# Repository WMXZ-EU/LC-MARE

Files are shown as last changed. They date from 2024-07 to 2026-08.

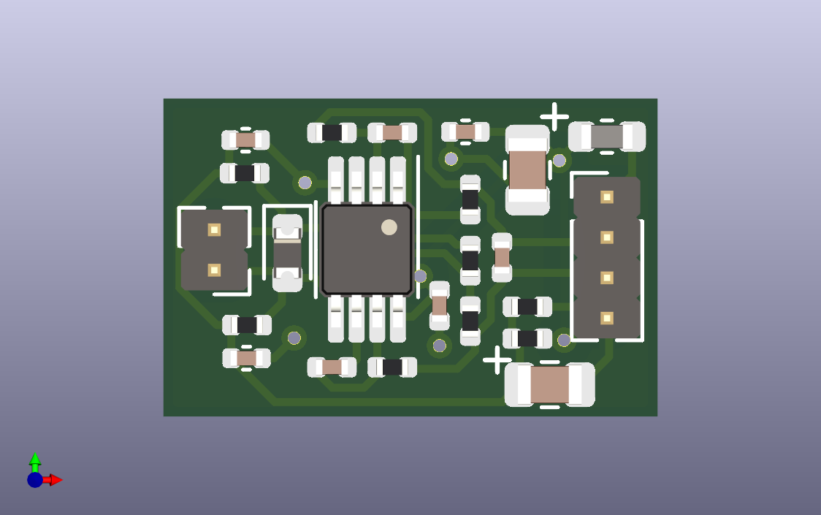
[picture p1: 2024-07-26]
KICAD/PreampV5-mare/PreampV5-mare.png

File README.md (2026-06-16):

# LC-MARE
Low-Cost Marine Acoustic REcorder. See detailed info in different folders
 
Actual preferred firmware verson is adalogger_V3

## Content
### 3D-models
contains some stl files for 3D printing
### adalogger_V2
first LC-Mare firmware uses only adalogger RP2040. Suitable for single hydrophone and sampling frequency up to 96 kHz
### adalogger_V3
improved LC-Mare firmware 
- for adalogger RP2040 (single hydrophone up to 96 kHz sampling frequency)
- for rp2350 based adafruit feather (stereo and up to 384 kHz sampling frequency)
### microPAM_V4
development version for three MCU types (RP2040, RP2350, Teensy4.1)
Work in Progress
### Documents
different files describing project and hardware construction
### KICAD
hardware desigh files for
- ADC (ADC_V2)
- preamp (PreampV5-mare)
- Base board (LC_PAMV4b)
- Libraries (for KICAD)
### Python
contains python based setup and analysis scripts

Of importance is a GUI (LC_Mare.py) that provides access to basic operations, like inspecting LC_mare file parameters, visualizing time series and spectra, to configure the firmware, to convert compressed to wav files, and to upload latest firmware

An compiled version (.exe) with supporting libraries may be found in

https://github.com/WMXZ-EU/LC-MARE/releases/download/LC_Mare_v1.0.0/LC_Mare.zip

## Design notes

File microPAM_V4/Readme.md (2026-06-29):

# microPAM V4

Firmware for a low-power **Passive Acoustic Monitor (PAM)** targeting three microcontroller boards. Records multi-channel audio via TDM (Time Division Multiplexed I2S) to SD card, with optional lossless integer compression, FFT-based directional sound intensity estimation, and online VAE-based acoustic classification.

Version: 4.3.0 — Copyright © 2026 Walter Zimmer. Released under the MIT License.

---

## Supported hardware

| Board | MCU | Channels | Max sample rate | DSP / Classifier |
|---|-----|---|---|---|
| Teensy 4.1 | i.MX RT1062 | 4 | 192 kHz | Yes (PROC_MODE 2 / 3 / 4) |
| Adafruit Feather RP2040 Adalogger | RP2040 | 1 | 192 kHz | No |
| Adafruit Feather RP2350 HSTX | RP2350 | 4 | 192 kHz | No |

All boards use a **TLV320ADC6140** analog front end (I2C configuration, programmable gain). The RP2350 board stores its deep DMA queue in 8 MB of on-board PSRAM.

ADC channel-count limits (hardware):

| `NCHAN_I2S` | Max `FSAMP` |
|---|---|
| 1 | 192 kHz |
| 2 | 384 kHz |
| > 2 | 192 kHz |

---

## Processing modes

Set `PROC_MODE` in [`config.h`](config.h):

| Value | Mode | Output file | Targets |
|---|---|---|---|
| 0 | Raw WAV | `.wav` | All |
| 1 | Integer compression (differential + bit-pack) | `.bin` | All |
| 2 | Compressed per-bin FFT magnitude spectrum | `.spc` | Teensy 4.1 only |
| 3 | Directional sound intensity (tetrahedral array) + compressed intensity vectors | `.int` | Teensy 4.1 only |
| 4 | DSP pipeline + 4-VAE classifier — latent means pushed to queue | `.vae` | Teensy 4.1 only |

PROC_MODE 2, 3, and 4 are silently downgraded to 1 on RP2040/RP2350 targets.

DSP modes (2 / 3 / 4) use asynchronous dispatch: `process()` snapshots the acquisition buffer and pends `IRQ_QTIMER3` (`DSP_IRQ_PRIORITY = 7×16`, below DMA) so the DMA ISR returns immediately. The DSP ISR performs the heavy computation and pushes results to the queue.

---

## Configuration

Edit [`config.h`](config.h) before building:

```c
#define T_ACQ   60    // recording window length (seconds)
#define T_ON     1    // on-time per duty cycle (minutes)
#define T_REP    0    // repeat interval; set < T_ACQ for continuous recording

#define FSAMP  192000 // sample rate (Hz)
#define PROC_MODE  4  // 0=raw WAV, 1=compressed, 2=spectrum, 3=intensity, 4=intensity+VAE (2/3/4: T4.1 only)

// #define USE_SYNTH_SIGNAL  // inject synthetic chirp every 100 calls (testing only)

// WAV file metadata
#define SRC_str "LC17"      // source/instrument ID
#define CMS_str "WMXZ"      // organisation
#define ART_str "WMXZ"      // creator
#define PRD_str "microPAM"  // product / activity
#define SBJ_str "______"    // area
#define NAM_str "Test"      // location ID
```

Key DSP/gain constants in [`src/global.h`](src/global.h):

```c
#define SHIFT  12    // bit-shift for integer compression
#define AGAIN  20    // ADC analogue gain (dB)
#define DGAIN   0    // ADC digital gain
```

Output scaling (in `src/process.cxx`):

| Mode | Scale factor | Formula |
|---|---|---|
| 2 (spectrum) | `scale2` | `1 << (31 − SHIFT)` |
| 3 / 4 (intensity) | `scale3` | `1 << (32 − SHIFT)` |

Detection parameters (PROC_MODE 3/4, Teensy 4.1):

```c
#define DETECT_ALPHA  0.01f  // background averaging rate (0.001 slow … 0.1 fast)
#define DETECT_THR    3.0f   // SNR threshold (Dblock / Dmean)
```

---

## DSP pipeline (Teensy 4.1, PROC_MODE 2 / 3 / 4)

```
process()            — snapshots acq_buffer → dsp_buffer, pends IRQ_QTIMER3 (async DSP ISR)
    │
    └─► dsp_isr()    — fires below DMA priority; does the heavy work per mode:
            │
            ├─ PROC_MODE 2 ─► spectrum_power()
            │                  spectrum_apply() — 50 %-overlap RFFT per channel → Z[]
            │                  per-bin magnitude sqrt(re²+im²) → scale2 → compress → queue (.spc)
            │
            └─ PROC_MODE 3/4 ─► dsp_apply()
                                 spectrum_apply()    — RFFT per channel → Z[]
                                 intensity_apply()   — cross-correlation → I[3×NSAMP], D[NSAMP]
                                 detection_apply()   — SNR, exponential background tracking
                                 classifier_trigger()— snapshot D[], pend IRQ_QTIMER4 (priority 128)
                                     │
                                     (ISR fires asynchronously)
                                 classifier_isr()    — 4 parallel VAE fwd+bwd+SGD on D_buf[] quarters
                                                     — exposes vae_mu[VAE_LAT_TOTAL], classifier_exec_us
                                 PROC_MODE 3: I[] → scale3 → compress → queue (.int)
                                 PROC_MODE 4: classifier ISR owns queue push of vae_mu → (.vae)
```

### VAE classifier (Teensy 4.1 only)

Four parallel online Variational Autoencoders, each trained incrementally on one quarter of the intensity spectrum `D[]`.

| Parameter | Value |
|---|---|
| Number of VAEs | 4 |
| Input per VAE (`VAE_QSAMP`) | `VAE_NSAMP / 4` (= 128 at 192 kHz, 4 ch) |
| Architecture per VAE | `QSAMP – 32 – 4 – 32 – QSAMP` |
| Latent dims per VAE (`VAE_LAT`) | 4 |
| Total exported latent means (`VAE_LAT_TOTAL`) | 16 |
| Learning rate | 1 × 10⁻⁴ (SGD) |
| KL weight β | 1 × 10⁻³ |
| Large weight storage | DMAMEM (RAM2) — W1[4][H][Q] and W4[4][Q][H] |
| IRQ | `IRQ_QTIMER4`, priority 128 |
| Model file | `/VAE_model.dat` on SD card root (loaded on boot, saved hourly and before hibernate) |
| Model backups | `/VAE_backup/VAE_model_YYYYMMDD_HHMM.dat` — timestamped snapshots |

All 16 latent means are available via `vae_mu[VAE_LAT_TOTAL]` (layout: `[vae0_μ0, …, vae0_μ3, vae1_μ0, …]`) and printed by the serial monitor each second. In PROC_MODE 4 they are also written to the `.vae` file via the queue.

---

## Architecture

```
Acquisition (DMA IRQ / core 1)
    └─► process()
            │  PROC_MODE 0: passthrough → queue
            │  PROC_MODE 1: differential encode + bit-pack → queue
            │  PROC_MODE 2/3/4: snapshot → pend IRQ_QTIMER3 (returns immediately)
            │
            └─► dsp_isr() [IRQ_QTIMER3, async]
                    │  PROC_MODE 2: spectrum magnitude → compress → queue
                    │  PROC_MODE 3: intensity → compress → queue
                    │  PROC_MODE 4: intensity → pend classifier ISR → queue (vae_mu)
                    └──────────────────────────────────────────────► queue

loop() / core 0
    └─► queue.pull() ──► logger() ──► SD card
```

- **RP2040 / RP2350**: acquisition on core 1 (`core1_main`); filing, RTC, and serial menu on core 0.
- **Teensy 4.1**: single-core; DMA ISR drives `process()` directly.
- The RP2350 queue (`MAX_QUEUE = 225`) is placed in PSRAM via a linker section attribute.

---

## Building

Requires [arduino-cli](https://arduino.github.io/arduino-cli/) installed at:

```
%LOCALAPPDATA%\Programs\Arduino IDE\resources\app\lib\backend\resources\arduino-cli.exe
```

Config directory: `%LOCALAPPDATA%\Arduino15`

```powershell
.\scripts\build.ps1            # all three targets
.\scripts\build.ps1 teensy     # Teensy 4.1 only
.\scripts\build.ps1 rp2040     # RP2040 Adalogger only
.\scripts\build.ps1 rp2350     # RP2350 HSTX only
```

Output goes to `build\<target>\`:

| Target | Binary | Format |
|---|---|---|
| Teensy 4.1 | `build\teensy\microPAM_V4.ino.hex` | Intel HEX (uploaded via Teensy Loader) |
| RP2040 | `build\rp2040\microPAM_V4.ino.uf2` | UF2 (drag-and-drop or arduino-cli) |
| RP2350 | `build\rp2350\microPAM_V4.ino.uf2` | UF2 (drag-and-drop or arduino-cli) |

> **RP2350 note:** always pass `psram=8mb` (the build script does this automatically). Without it the linker fails because the default `psram_length` is 0.

---

## Flashing (compile + upload)

```powershell
.\scripts\flash_teensy.ps1     # Teensy 4.1 — board must be connected
.\scripts\flash_rp2040.ps1     # RP2040 — normal connection or BOOTSEL+plug
.\scripts\flash_rp2350.ps1     # RP2350 HSTX — normal connection or BOOTSEL+plug
```

RP scripts try two paths in order:
1. BOOTSEL mass-storage drive (`RPI-RP2` / `RP2350`) — copies the `.uf2` directly.
2. Serial port — arduino-cli resets the board into the bootloader.

## Uploading pre-built firmware (upload only)

If you have received pre-built binaries (or already compiled with `build.ps1`) and only need to flash them without recompiling, use the upload-only scripts:

```powershell
.\scripts\upload_teensy.ps1    # Teensy 4.1
.\scripts\upload_rp2040.ps1    # RP2040 Adalogger
.\scripts\upload_rp2350.ps1    # RP2350 HSTX
```

These scripts read the binary directly from `build\<target>\` and abort with a clear message if no pre-built file is found there. The same two-path upload logic applies to the RP boards (BOOTSEL drive first, then serial port).

**Steps to flash a pre-built binary:**

1. Copy the `build\` folder (or the relevant sub-folder) from the source that provided the firmware onto your machine, keeping the path structure intact.
2. Connect the board:
   - **Teensy 4.1**: connect via USB; press the PROGRAM MODE button if prompted during upload.
   - **RP2040 / RP2350**: connect normally, or hold the **BOOTSEL** button while plugging in to force mass-storage mode.
3. Open a PowerShell terminal in the `microPAM_V4` directory and run the appropriate script:
   ```powershell
   .\scripts\upload_teensy.ps1   # or upload_rp2040.ps1 / upload_rp2350.ps1
   ```
4. Wait for `Upload OK`.

---

## Python tools

Three companion tools are provided in the `Python/` folder.  All require Python 3.10+ and the packages listed in `Python/requirements.txt`.

A ready-to-use virtual environment is included at `Python/.venv` (Python 3.14).  Install dependencies once with:

```powershell
Python\.venv\Scripts\pip.exe install -r Python\requirements.txt
```

To run from PyCharm, set the interpreter to `Python\.venv\Scripts\python.exe`.

See [`Docs/micropam_python_tools.md`](Docs/micropam_python_tools.md) for a full user guide.

### micropam_control — device configuration GUI

Configures and controls the PAM over USB serial without a terminal.

```powershell
Python\.venv\Scripts\python.exe Python\micropam_control.py
```

| GUI element | Serial command | Description |
|---|---|---|
| Port / Connect | — | Lists available COM ports; connects at 115200 baud (USB CDC, baud ignored) |
| UID display | `?u` | Board unique ID, fetched automatically on connect |
| t_acq / t_on / t_rep | `?a` / `!a` … | Recording timing parameters |
| fsamp | `?f` / `!f` | Sampling frequency |
| again | `?g` / `!g` | ADC analogue gain (dB) |
| Artist / Product / Name | `?n` / `!n` … | WAV metadata strings |
| Start Time | `?x` / `!x` | Scheduled start time string |
| h_rec 1–4 | `?1`…`?4` / `!1`…`!4` | Recording hour windows |
| Datetime / getRTC | `?d` | Read current RTC time from MCU into the field |
| Datetime / Set RTC | `!d` | Send the Datetime field value to the MCU RTC |
| Datetime / syncRTC | `!d` | Stamp PC time → field → MCU RTC in one click |
| Read all | all `?` keys | Queries every parameter and populates the GUI |
| Start / Stop | `s` / `e` | Start or stop acquisition |
| Print params | `p` | Print all parameters to the serial monitor |
| Reboot | `b` | Reboot the MCU |
| Hibernate hours / minutes | `x<n>` / `y<n>` | Enter low-power sleep |
| Raw send box | passthrough | Send any command directly |
| Serial monitor | — | Full-width scrolling output, auto-parses `key = value` responses |

### micropam_browser — data file browser and viewer

Browse, inspect, and visualise recorded data files without any additional software.

```powershell
Python\.venv\Scripts\python.exe Python\micropam_browser.py [folder]
```

Features:

- Sortable file list with mode, sample rate, channel count, and file size
- Right-click (or double-click) any file → **Show header info** — full WAV/IKEY parameter popup
- Right-click → **View data** (or press `v`) — mode-specific matplotlib plot:
  - **Mode 0/1**: time series per channel + spectrogram of channel 0
  - **Mode 2**: per-channel compressed spectrum waterfall
  - **Mode 3**: directional intensity — magnitude + Ix / Iy / Iz log-scaled waterfalls
  - **Mode 4**: detection excess + 4 VAE anomaly score time series

### micropam_reader — Python API

Programmatic access to all file formats:

```python
from micropam_reader import MicroPAMFile

result = MicroPAMFile("recording.int").read_all()
data   = result["data"]   # numpy array, shape depends on PROC_MODE
```

### vae_model_analysis — VAE model report

Reads all `VAE_model_*.dat` snapshots from the SD card's `/VAE_backup/` folder and generates a 5-page PDF report showing background model convergence, weight norm evolution, and latent space drift.

```powershell
Python\.venv\Scripts\python.exe Python\vae_model_analysis.py <path-to-VAE_backup>
```

---

## Key source files

| File | Role |
|---|---|
| [`config.h`](config.h) | User-facing settings: sample rate, proc mode, metadata |
| [`src/global.h`](src/global.h) | Per-MCU constants: channel counts, buffer sizes, queue depth, gain |
| [`src/process.cxx`](src/process.cxx) | Queue, compression, async DSP dispatch (IRQ_QTIMER3), spectrum/intensity/detection, classifier trigger |
| [`src/classifier.cxx`](src/classifier.cxx) | 4 parallel online VAEs: forward pass, backprop, SGD, ISR, queue push (mode 4) |
| [`src/utils.cxx`](src/utils.cxx) | Print helpers, `synth_chirp_generate()` for synthetic test signal injection |
| [`src/utils.h`](src/utils.h) | Declarations for print helpers and synth chirp generator |
| [`src/classifier.h`](src/classifier.h) | VAE architecture constants, public API, `vae_mu`, `classifier_exec_us` |
| [`src/adc.cxx`](src/adc.cxx) | TLV320ADC6140 I2C init, gain control |
| [`src/rp2x.cxx`](src/rp2x.cxx) | RP2040/RP2350 PIO TDM, DMA, hibernate, RTC, NeoPixel |
| [`src/Teensy.cxx`](src/Teensy.cxx) | Teensy SAI/I2S, DMA, hibernate (SNVS), UID |
| [`src/filing.cxx`](src/filing.cxx) | SD logger, WAV/bin/dat/vae header writer, config file load/save |
| [`src/rtc.cxx`](src/rtc.cxx) | RV3028 external RTC, internal RTC, time conversion, alarm |
| [`src/menu.cxx`](src/menu.cxx) | Serial menu: start/stop/parameters, `?` query / `!` set protocol |
| [`Python/micropam_control.py`](Python/micropam_control.py) | Python/tkinter device configuration and control GUI |
| [`Python/micropam_browser.py`](Python/micropam_browser.py) | Python/tkinter data file browser and visualiser |
| [`Python/micropam_reader.py`](Python/micropam_reader.py) | Python API for reading all microPAM file formats |
| [`Python/simulator.py`](Python/simulator.py) | Pure-Python simulator mirroring full firmware chain; Wenz ocean noise model + synthetic chirp injection |
| [`Python/vae_model_analysis.py`](Python/vae_model_analysis.py) | Analyses `/VAE_backup/` snapshots from SD card; generates 5-page PDF report |

---

## Toolchain version notes

- **Teensy 4.1**: TeensyDuino ≤ 1.61.0 required (as of June 2026).
- **RP2040 / RP2350**: arduino-mbed-rp2040 core 5.6.0 works correctly.
- **Python GUI**: Python 3.x + pyserial 3.5; venv at `Python\.venv`.

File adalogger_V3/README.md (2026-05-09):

# adalogger
 This directory contains the V3 source code for the LC-MARE project. 
 Further documentation on this project, basic Analysis scripts and Hardware description may be found in the parent folder.

 The menu is minimized to start/end acquisition, correct external RTC and to print actual acquisition parameters. 
 It is expected that the user adapts the acquisition parameters in config.h and recompiles the program.

## Menu
 The menu commands are 
 - s: start acquisition
 - e: end acquisition
 - c: check and change RTC
 - p: print system and acquisition parameters 
 - x: reboot system (adding to x a number hibernates the system [eg, x 1 hibernates and restarts at the next full hour] )

    parameter settings
 - !a xx: set squisition (file length) to xx seconds
 - !o x: set on time to x minutes (sic!)
 - !r x: set repetition rate to x minutes (sic!) continuous if "rep rate" < "on time"
 - !f x: set sampling frequency in Hz
 - !g x: set analog gain in dB
 - !w x: set eeprom mode to x (0: stored but not to be used, 1: stored and to be used on reboot)
 
 ## Run configuration
 The run configuration is controlled by config.h

 ## Sytem configuration
 System configuration is controlled by src/global.h

## Miscalaneous
  - program developed for TMS320ADC6140 ADC, but derived from program for MEMS I2S microphone 
  - external RTC is RV2038
  - integer compression (PROC = 1)

## (main) differences to adalogger_V2
  - Using of queue to bridge miscroSD card latencies
  - compression (PROC=1) is carried out on acq core (core #1)

## UF2 file
 Direct link to uf2 file: 
 
 For RP2040 Adalogger
 - https://github.com/WMXZ-EU/LC-MARE/blob/main/adalogger_V3/build/rp2040.rp2040.adafruit_feather_adalogger/adalogger_V3.ino.uf2
 
 For RP2350 Feather
 - https://github.com/WMXZ-EU/LC-MARE/blob/main/adalogger_V3/build/rp2040.rp2040.adafruit_feather_rp2350_hstx/adalogger_V3.ino.uf2
 
 ## Upgrade firmware
 - copy UF2 file (e.g. as above from Github) to local PC
 - disconnect battery 
 - connect usb to PC
 - Press boot button (furthest button from usb connector)
 - while pressed, press shortly reset button (closest button from usb connector)
 - release boot button
 - on PC there should be a new disk showing up call uf2
 - if not automatically opened, open this disk
 - copy/drag UF2 file into this disk/folder
 - once the file is completely copied, folder/disk will disappear and mcu will restart with new firmware

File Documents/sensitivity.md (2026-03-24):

% Hydrophone Sensitivity
% Walter MX Zimmer
% 22-03-2026

Contents:

<!-- TOC -->
* [Reference](#reference)
* [Cylinder](#cylinder)
  * [Lamé equations](#lamé-equations)
* [Electric field](#electric-field)
  * [Note:](#note)
  * [generated voltage](#generated-voltage)
* [Sphere](#sphere)
<!-- TOC -->

## Reference
https://engineeringlibrary.org/reference/thick-pressure-vessels-air-force-stress-manual

https://apps.dtic.mil/sti/pdfs/AD0759199.pdf

## Cylinder
Given a cylider with a,b as internal,external radius stress is given by the  Lamé equations.

### Lamé equations
For cylinder we have the following stress equations

#### radial tension
$$
T_3(r)=A-\frac{B}{r^2}
$$

#### circumferential tension
$$T_1(r)=A+\frac{B}{r^2}
$$

#### axial tension (end-capped cylinder)
$$T_2(r)=A
$$
whereby
$$A=\frac{P_aa^2-P_bb^2}{b^2-a^2}
$$
$$
B=\frac{a^2b^2(P_a-P_b)}{b^2-a^2}
$$

Assume for hydrophones internal pressure $P_a=0$, then the two constants $A$ and $B$ become
$$
A=-P_b\frac{b^2}{b^2-a^2}
$$
$$
B=-P_b\frac{a^2b^2}{b^2-a^2} = Aa^2
$$

and the three stress equations are then
$$
T_3(r)=A(1-\frac{a^2}{r^2})
$$
$$
T_1(r)=A(1+\frac{a^2}{r^2})
$$
$$
T_2(r)=A
$$
with $A$ as defined above

## Electric field
The electric field in radial direction $E_3(r)$ due to external pressure becomes with $g_{32}=g_{31}$
$$
E_3(r)=-g_{31} (T_1(r)+T_2(r))-g_{33} T_3(r)
$$
and the measured voltage $V$
$$
V = \int_a^b{E_3(r)dr}
$$

### Note:
$$
\int_a^b{dr} = b-a
$$
$$
\int_a^b{\frac{1}{r^2}dr} = -(\frac{1}{b}-\frac{1}{a})=\frac{b-a}{ab}
$$
that is
$$
\int_a^b(1\pm {\frac{a^2}{r^2}})dr =(b-a)\pm\frac{a(b-a)}{b}=(b-a)(1\pm\frac{a}{b})
$$

### Generated voltage
$$
V =-\int_a^b{(g_{31} (T_1(r)+T_2(r))+g_{33} T_3(r))dr}
$$
$$
V =-A(b-a)\big(g_{31}(2+\frac{a}{b})+g_{33}(1-\frac{a}{b})\big)
$$
$$
V =-P_b b \frac{b}{b+a}\big(g_{31}(2+\frac{a}{b})+g_{33}(1-\frac{a}{b})\big)
$$

Let $t=\frac{a}{b}$ then
$$
V =-P_b b \frac{1}{1+t}\big(g_{31}(2+t)+g_{33}(1-t)\big)
$$

## Sphere
$$
T_3(r)=P_b\frac{b^3}{a^3-b^3}(1-\frac{a^3}{r^3})
$$
$$
T_1(r)=T_2(r)=P_b\frac{b^3}{a^3-b^3}(1+\frac{a^3}{2r^3})
$$

With
$$
\int_a^b{\frac{1}{r^3}dr} = -\frac{1}{2}(\frac{1}{b^2}-\frac{1}{a^2})=\frac{1}{2}\frac{b^2-a^2}{a^2b^2}=\frac{1}{2}(\frac{b+a}{ab})(\frac{b-a}{ab})
$$
and therefore
$$
\int_a^b(1- \frac{a^3}{r^3})dr =(b-a)-\frac{a^3}{2}\frac{b+a}{ab}\frac{b-a}{ab}=(b-a)(1-\frac{a}{2b}\frac{b+a}{b})
=\frac{(b-a)}{2}(2-\frac{a}{b}-\frac{a^2}{b^2})
$$
$$
\int_a^b(1+ \frac{1}{2}\frac{a^3}{r^3})dr =(b-a)+\frac{1}{2}\frac{a^3}{2}\frac{b+a}{ab}\frac{b-a}{ab}=(b-a)(1+\frac{1}{2}\frac{a}{2b}\frac{b+a}{b})=\frac{(b-a)}{4}(4+\frac{a}{b}+\frac{a^2}{b^2})
$$
one gets
$$
V = -P_b\frac{b^3}{b^3-a^3}\frac{(b-a)}{2}\big(g_{31}(4+\frac{a}{b}+\frac{a^2}{b^2})+g_{33}(2-\frac{a}{b}-\frac{a^2}{b^2})\big)
$$
and finally
$$
V = -P_b\frac{b}{2}\frac{b^2}{b^2+ab+a^2}\big(g_{31}(4+\frac{a}{b}+\frac{a^2}{b^2})+g_{33}(2-\frac{a}{b}-\frac{a^2}{b^2})\big)
$$
which again is equivalent to
$$
V = -P_b\frac{b}{2}\frac{1}{1+t+t^2}\big(g_{31}(4+t+t^2)+g_{33}(2-t-t^2)\big)
$$

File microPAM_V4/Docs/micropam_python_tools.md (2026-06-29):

# microPAM Python Tools — User Guide

This document describes the three Python companion tools supplied with microPAM V4:

| Tool | File | Purpose |
|---|---|---|
| **micropam_control** | `Python/micropam_control.py` | Configure and control a connected PAM over USB serial |
| **micropam_browser** | `Python/micropam_browser.py` | Browse, inspect, and visualise recorded data files |
| **micropam_reader** | `Python/micropam_reader.py` | Python API / command-line decoder for all file formats |
| **vae_model_analysis** | `Python/vae_model_analysis.py` | Analyse VAE model snapshots from SD card; generates PDF report |

---

## Requirements

Python 3.10 or newer.  A ready-to-use virtual environment is provided at `Python/.venv`.

Install or update dependencies:

```powershell
Python\.venv\Scripts\pip.exe install -r Python\requirements.txt
```

| Package | Minimum version | Used by |
|---|---|---|
| numpy | 2.0 | reader, browser |
| matplotlib | 3.9 | browser (data plots) |
| pyserial | 3.5 | control |
| scipy | 1.13 | optional, not required at runtime |

To use the tools from PyCharm, set the project interpreter to `Python\.venv\Scripts\python.exe`.

---

## micropam_control

### Overview

`micropam_control.py` is a tkinter GUI that communicates with a microPAM device over its USB serial port.  It implements the `?` (query) / `!` (set) serial protocol defined in `src/menu.cxx`, presenting all device parameters as labelled fields that can be read and written with a single click.

### Running

```powershell
Python\.venv\Scripts\python.exe Python\micropam_control.py
```

### Connection

1. Connect the PAM to the PC via USB.
2. Open the **Port** drop-down and select the device COM port (e.g. `COM5`).
3. Click **Connect**.  The UID field is populated automatically.

The GUI connects at 115200 baud, but microPAM uses USB CDC so the baud rate is ignored by the device.

Click **Disconnect** before unplugging or when finished.

### Parameter panels

#### Recording timing

| Field | Command | Description |
|---|---|---|
| t_acq | `?a` / `!a` | Acquisition window length in seconds |
| t_on | `?o` / `!o` | On-time per duty cycle in minutes |
| t_rep | `?r` / `!r` | Repeat interval; 0 = continuous |

#### Signal

| Field | Command | Description |
|---|---|---|
| fsamp | `?f` / `!f` | Sample rate (Hz) |
| again | `?g` / `!g` | ADC analogue gain (dB) |

#### File metadata (written into WAV INFO chunks)

| Field | Command | Description |
|---|---|---|
| Artist | `?n` / `!n` | Creator / organisation |
| Product | `?p` / `!p` | Project or instrument type |
| Name | `?m` / `!m` | Location or station ID |
| Start Time | `?x` / `!x` | Scheduled start time string |

#### Hour windows

`h_rec[0]`–`h_rec[3]` define up to four daily recording windows (start–stop hour pairs).  Read with `?1`…`?4`, write with `!1`…`!4`.

#### RTC / datetime

| Button | Command | Action |
|---|---|---|
| getRTC | `?d` | Read MCU RTC time into the Datetime field |
| Set RTC | `!d` | Write the Datetime field to the MCU RTC |
| syncRTC | `!d` | Stamp current PC time into the field and send to MCU in one click |

#### Bulk operations

| Button | Action |
|---|---|
| **Read all** | Queries every `?` command and fills the entire GUI |
| **Start** | Sends `s` — begins recording |
| **Stop** | Sends `e` — ends recording |
| **Print params** | Sends `p` — prints all parameters to the serial monitor |
| **Reboot** | Sends `b` — reboots the MCU |

#### Hibernate

Enter `n` hours and `m` minutes in the hibernate fields then click **Hibernate** to send `x<n>` and `y<m>` and put the device into low-power sleep.

#### Raw command entry

The **Raw send** box accepts any single character or command string and sends it verbatim on Return.  Responses appear in the serial monitor below.

### Serial monitor

The full-width pane at the bottom shows all bytes received from the device.  Lines of the form `key = value` are automatically parsed and, where a matching GUI field exists, the field is updated.

---

### How to configure duty cycling

Duty cycling makes the PAM record for a fixed on-time window and then hibernate until the next cycle repeats.  The timing is controlled by two parameters:

| Parameter | Meaning |
|---|---|
| **t_on** | How long the device records each cycle (minutes) |
| **t_rep** | Cycle length — recording starts every `t_rep` minutes.  The device hibernates for `t_rep − t_on` minutes between files.  Set `t_rep = 0` (or `t_rep < t_acq / 60`) to disable duty cycling and record continuously. |

**Steps using micropam_control:**

1. Connect to the device (select port → **Connect**).
2. Click **Read all** to populate the current settings.
3. Enter the desired value in the **t_on** field (e.g. `2` for 2 minutes of recording per cycle).
4. Enter the desired value in the **t_rep** field (e.g. `5` for a 5-minute cycle, giving 3 minutes of sleep).
5. Press **Return** or click the adjacent set button next to each field to send `!o <value>` and `!r <value>` to the device.
6. Click **Reboot** (sends `b`) — the device restarts and immediately applies the new duty-cycle settings read from its config file on the SD card.

The settings are automatically saved to `config.txt` on the SD card when the device reboots or when recording stops, so they persist across power cycles.

To disable duty cycling, set **t_rep** back to `0` and reboot.

> **Important:** USB serial communication is only possible while the device is awake and recording.  During the hibernate interval the device is powered down and cannot be reached.  If you need to change or disable duty cycling you must either wait for the device to wake up at the start of its next on-window, or power-cycle it while holding **BOOTSEL** to force it into bootloader mode and then reflash the firmware with `T_REP = 0` compiled in.

---

## micropam_browser

### Overview

`micropam_browser.py` is a tkinter file browser that lists microPAM data files (`.wav`, `.bin`, `.spc`, `.int`, `.vae`), shows key header parameters in a sortable table, and opens interactive matplotlib plots when a file is selected.

### Running

```powershell
Python\.venv\Scripts\python.exe Python\micropam_browser.py [folder]
```

If `folder` is omitted the browser opens in the current working directory.

### File list

The table shows one row per file with the following columns:

| Column | Content |
|---|---|
| File | Filename |
| Size | File size (bytes / KB / MB) |
| Modified | Last-modified timestamp |
| Mode | PROC_MODE number and label |
| fsamp | Sample rate (Hz) |
| nch | Number of channels |
| Dur / Size | Duration for mode 0 (computed from file size); raw data size for compressed modes |

Click a column header to sort; click again to reverse.

### Navigation

| Control | Action |
|---|---|
| **Up** | Navigate to parent folder |
| **Refresh** | Re-scan the current folder |
| **Open folder…** | Pick a folder with a file-chooser dialog |
| Directory entry | Shows the current path (read-only) |

### Right-click menu

Right-click any row (or double-click, or press Return / `v`) to open:

| Menu item | Action |
|---|---|
| **Show header info** | Opens a scrollable popup with all WAV and IKEY parameters parsed from the file header |
| **View data** | Opens a matplotlib plot window for the file (see below) |
| **Open containing folder** | Opens the file's parent folder in Windows Explorer |

### Header popup

Displays all parameters extracted from the 512-byte WAV header:

- File path, size, and modification time
- WAV format: channels, sample rate, bit depth
- IKEY acquisition parameters: PROC_MODE, UID, version, sample rate, gain, SHIFT, NBUF_PROC, NAVG, t_acq, t_on, t_rep, h_rec
- Recording start time parsed from the filename
- INFO chunk tags

Scroll horizontally and vertically; press **Escape** or **Close** to dismiss.

### Data viewer

The **View data** window embeds a matplotlib figure with a standard navigation toolbar (zoom, pan, home, save).  Layout depends on PROC_MODE:

#### Mode 0 — Raw WAV / Mode 1 — Compressed PCM

- **Top half** (stacked): one time-series subplot per channel, all sharing the same x-axis (time in seconds).
- **Bottom half**: STFT spectrogram of channel 0 (512-point Hann window, 50 % overlap, 60 dB dynamic range), sharing the same x-axis as the time series above.  A colour bar shows the dB scale.

Panning or zooming in time synchronises all panels.

#### Mode 2 — Compressed spectrum (SPC)

`nch` spectrogram panels stacked vertically, one per channel.  Each panel shows frequency (Hz) on the y-axis and frame index on the x-axis, colour-mapped to signal magnitude in dB.  All panels share x and y axes; each has its own colour bar.

#### Mode 3 — Directional intensity (INT)

Four panels stacked vertically, all sharing axes:

1. **|I|** — instantaneous intensity magnitude, log₁₀(|I| + 1), *inferno* colourmap.
2. **Ix** — x-component, signed log, *RdBu_r* colourmap (blue = negative, red = positive).
3. **Iy** — y-component, same scale.
4. **Iz** — z-component, same scale.

Each panel has a colour bar.  The logarithmic scale is necessary because acoustic intensity data is highly sparse (~98 % of bins are near zero at any given moment).

#### Mode 4 — VAE classifier (VAE)

Five time-series panels stacked vertically, all sharing the x-axis (time in seconds from the start of the file):

1. **Detection excess** — `Dsnr − DETECT_THR`.  Positive values (shaded) indicate frames where the background-normalised intensity exceeded the detection threshold (default 3.0).  A dashed red line marks zero.
2–5. **VAE 0–3** — per-VAE anomaly score `‖μ − μ_bg‖ × (err / err_bg)`.  All four panels share the same y-axis, scaled to 110 % of the overall maximum score.  A grey dashed line on each panel marks the noise-frame `mean + 3σ` threshold for that VAE, computed from frames where `signal_flag == 0`.

---

## vae_model_analysis — VAE model snapshot report

### Overview

`vae_model_analysis.py` reads a folder of timestamped VAE model backups written by the firmware (`/VAE_backup/VAE_model_YYYYMMDD_HHMM.dat` on the SD card) and produces a multi-page PDF report showing how the background model evolved over a deployment session.

### Running

```powershell
Python\.venv\Scripts\python.exe Python\vae_model_analysis.py <folder>
```

If `folder` is omitted, the current directory is used.  The output file `vae_model_report.pdf` is written to the same folder.

### Additional requirements

```powershell
Python\.venv\Scripts\pip.exe install matplotlib
```

(numpy and matplotlib are required; both are available in the default `.venv`.)

### Output

A 5-page PDF:

| Page | Content |
|---|---|
| 1 | Summary: file list with per-file statistics, key findings paragraph |
| 2 | `recon_bg` on a log scale per VAE — rapid convergence is visible in the first hour |
| 3 | Frobenius norms of W4 (solid) vs W1 (dotted) — W1 is frozen; W4 adapts slowly |
| 4 | Mean `mu_bg` per VAE — reveals slow diel drift of the ambient background |
| 5 | `mu_bg` by latent dimension for VAE 0 — shows spectral feature encoding |

### Workflow

1. Remove the SD card from the PAM after a deployment session.
2. Copy the `/VAE_backup/` folder from the SD card to your PC (e.g. into `data/VAE_backup`).
3. Run the script:
   ```powershell
   Python\.venv\Scripts\python.exe Python\vae_model_analysis.py data\VAE_backup
   ```
4. Open `data\VAE_backup\vae_model_report.pdf`.

---

## micropam_reader — Python API

`micropam_reader.py` is a self-contained library (no dependencies other than numpy) that reads all five microPAM file formats.

### Quick start

```python
from micropam_reader import MicroPAMFile

# Read header only
f   = MicroPAMFile("recording.int")
print(f.info["proc_mode"], f.info["sample_rate"])

# Read all data at once
result = f.read_all()
data   = result["data"]        # numpy array
millis = result["millis"]      # list of firmware timestamps (ms)

# Stream block by block (memory-efficient for large files)
with MicroPAMFile("recording.wav") as f:
    for block in f.iter_blocks():
        pcm = block["data"]    # int32 ndarray, shape (nframes, nch)
```

### Return format by PROC_MODE

| Mode | `data` dtype | `data` shape | Extra keys |
|---|---|---|---|
| 0 | int32 | (nframes, nch) | — |
| 1 | int32 | (nframes, nch) | — |
| 2 | int32 | (nsamp×n_rec, nch) | — |
| 3 | int32 | (nsamp×n_rec, nch) | — |
| 4 | float32 | alias for `vae_mu` | `signal_flag`, `detection_excess`, `vae_detect`, `vae_mu`, `I` |

For mode 4, `read_all` returns a dict with:

| Key | dtype | Shape | Content |
|-----|---|---|---|
| `millis` | list[int] | (N,) | Firmware timestamp per frame (ms) |
| `signal_flag` | int8 | (N,) | 1 = detection, 0 = noise |
| `detection_excess` | float32 | (N,) | Dsnr − DETECT_THR |
| `vae_detect` | float32 | (N, 4) | Per-VAE anomaly score |
| `vae_mu` | float32 | (N, 16) | VAE latent means (4 VAEs × 4 dims) |
| `I` | float32 | (N, 3, 512) | Intensity matrix; zeros on noise frames |

### Command-line usage

```powershell
Python\.venv\Scripts\python.exe Python\micropam_reader.py <file> [block_words]
```

Prints header parameters and decoded data statistics (shape, min/max, record count).

---

*microPAM V4 — Copyright © 2026 Walter Zimmer. Released under the MIT License.*

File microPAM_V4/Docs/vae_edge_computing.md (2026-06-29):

# Online VAE-Based Acoustic Event Detection on a Microcontroller Edge Device

**Walter Zimmer** — microPAM V4, 2026

---

## Abstract

We describe an online Variational Autoencoder (VAE) system for acoustic event detection and classification running in real time on a Teensy 4.1 ARM Cortex-M7 microcontroller at 192 kHz sampling rate.  The key design principle is that the models learn exclusively from background noise frames and are frozen during detected events, so that the learned latent space represents the ambient acoustic environment rather than any specific signal class.  Event detection is provided by a separate SNR tracker; the VAE anomaly score then characterises how far a detected frame departs from the learned background.  Four parallel VAEs each specialise on one quarter of the directional intensity spectrum, giving spatially and spectrally resolved representations with a total of 16 exported latent means per processing frame.  A Python simulator mirrors the full firmware chain — including a physically motivated ocean ambient noise model — and is used to validate the architecture before deployment.  The trained model is persisted to the SD card and restored across power cycles and hibernation intervals, enabling long-term autonomous deployment.

---

## 1. Introduction

Battery-operated Passive Acoustic Monitors (PAMs) deployed for weeks to months must detect and log acoustic events without human supervision, with severe constraints on compute, memory, and power.  Classical approaches either record raw audio (large storage, no onboard intelligence) or apply fixed-threshold detectors (brittle to changing ambient conditions).

Machine learning on the edge offers a middle path: a model that adapts continuously to the local noise environment and flags departures from it as candidate events.  Autoencoders are well suited to this task because they can be trained unsupervised on unlabelled background data and produce an anomaly score — the reconstruction error — that rises when the input no longer resembles the training distribution.  Variational Autoencoders additionally structure the latent space to be compact and smooth, which helps distinguish event classes by their position in latent space.

The key constraint distinguishing our setting from offline deep learning is that training and inference must interleave in real time, at the pace of the acoustic acquisition loop, within the interrupt budget of a single microcontroller core.

---

## 2. Hardware and Signal Chain

### 2.1 Platform

The Teensy 4.1 (NXP i.MX RT1062, ARM Cortex-M7 at up to 600 MHz) hosts a four-channel TDM ADC front end (TLV320ADC6140) arranged as a tetrahedral microphone array.  Raw audio arrives via DMA at 192 kHz; each DMA half-buffer contains 2048 interleaved 32-bit samples (512 samples per channel).  An SD card stores compressed data files and configuration.

### 2.2 Acoustic Preprocessing

Each DMA completion triggers `process()`, which snapshots the acquisition buffer and pends an asynchronous DSP interrupt (`IRQ_QTIMER3`, priority below DMA) so the acquisition loop returns immediately.  Inside the DSP ISR, the following chain runs:

**Spectral analysis.** A 50%-overlap RFFT (1024-point Hann-windowed FFT, ARM CMSIS-DSP `arm_rfft_fast_f32`) is applied to each channel independently.  The output `Z[k, ch]` holds complex spectral coefficients for frequency bin *k* and channel *ch*.

**Directional sound intensity.** For each frequency bin *k*, the imaginary part of the cross-spectrum between every channel pair is computed:

$$\mathrm{Im}(\overline{Z_a} \cdot Z_b) = Z_{a,\mathrm{re}} \cdot Z_{b,\mathrm{im}} - Z_{a,\mathrm{im}} \cdot Z_{b,\mathrm{re}}$$

A fixed mixing matrix **M** (3 × 6) derived from the tetrahedral geometry projects the six pairwise cross-spectra onto three Cartesian intensity components $I_x[k], I_y[k], I_z[k]$.  The intensity magnitude spectrum is

$$D[k] = \sqrt{I_x[k]^2 + I_y[k]^2 + I_z[k]^2}$$

$D$ encodes both spectral energy and spatial directionality and serves as the VAE input.

### 2.3 Background Detection

Before the VAE is invoked, a simple SNR tracker decides whether the current frame is a noise frame or a signal frame:

$$D_\mathrm{block} = \frac{1}{N}\sum_{k=0}^{N-1} D[k]$$

$$D_\mathrm{mean} \mathrel{+}= \alpha \cdot (D_\mathrm{block} - D_\mathrm{mean}) \quad \text{(EMA, noise frames only)}$$

$$D_\mathrm{snr} = D_\mathrm{block} \;/\; D_\mathrm{mean}$$

with $\alpha = 0.01$ (slow adaptation, memory ≈ 100 frames ≈ 27 s at 192 kHz) and detection threshold $\Theta = 3.0$.  The background estimate is updated 10× more slowly on potential signal frames to protect it from contamination.

---

## 3. Online VAE Classifier

### 3.1 Architecture

Four VAEs run in parallel, each receiving one quarter of the 512-bin intensity spectrum $D$ (128 bins per VAE, covering contiguous non-overlapping sub-bands).  Each VAE has a symmetric encoder–decoder architecture:

$$\text{input } Q \xrightarrow{\text{ReLU}} H \xrightarrow{} \mu, \log\sigma^2 \xrightarrow{\text{reparam.}} z \xrightarrow{\text{ReLU}} H \xrightarrow{} \hat{D}$$

with $Q = 128$ (input bins per VAE), $H = 32$ (hidden width), $L = 4$ (latent dimensions per VAE), giving a total of $4 \times 4 = 16$ latent means exported per frame.

| Layer | Parameters | Size (float32) |
|---|---|---|
| W1 [4][H][Q] | encoder input | 64 KB (DMAMEM) |
| W4 [4][Q][H] | decoder output | 64 KB (DMAMEM) |
| Wmu, Wlv [4][L][H] | mu / log-var heads | 8 KB |
| W3 [4][H][L] | decoder hidden | 2 KB |
| b1, b3, b4, bmu, blv | biases | 4 KB |
| **Total** | | **≈ 142 KB** |

The two large weight matrices W1 and W4 are placed in DMAMEM (RAM2) to avoid pressure on tightly coupled RAM1.

### 3.2 Training Loss

The loss per VAE is the standard ELBO with reconstruction term (MSE) and KL regulariser:

$$\mathcal{L}_v = \underbrace{\frac{1}{Q}\sum_{j=0}^{Q-1}(\hat{D}_j - D_j)^2}_{\text{MSE}} + \beta \underbrace{\frac{1}{2}\sum_{l=0}^{L-1}\bigl(e^{\sigma^2_l} + \mu_l^2 - 1 - \sigma^2_l\bigr)}_{\text{KL}}$$

with $\beta = 10^{-3}$ and learning rate $\eta = 10^{-4}$ (SGD).  Weight initialisation uses Xavier uniform scaling.

### 3.3 Background-Only Learning

**The central design choice** is that the backward pass (weight update) runs only on noise frames ($D_\mathrm{snr} < \Theta$).  On signal frames the forward pass runs for inference but gradients are suppressed.  This ensures the VAE latent space represents ambient background conditions; acoustic events produce anomalous encoder outputs precisely because the network has never been trained on them.

In parallel, a per-VAE exponential moving average tracks the background latent position and reconstruction quality:

$$\mu_{\mathrm{bg},v} \mathrel{+}= \alpha \cdot (\mu_v - \mu_{\mathrm{bg},v})$$
$$\varepsilon_{\mathrm{bg},v} \mathrel{+}= \alpha \cdot (\varepsilon_v - \varepsilon_{\mathrm{bg},v})$$

where $\varepsilon_v$ is the per-VAE MSE reconstruction error and updates are restricted to noise frames.

### 3.4 Anomaly Score

The per-VAE anomaly score combines latent deviation from the background with elevated reconstruction error:

$$s_v = \|\mu_v - \mu_{\mathrm{bg},v}\| \;\times\; \frac{\varepsilon_v}{\varepsilon_{\mathrm{bg},v}}$$

This score is near zero for noise frames (small latent shift, normal error) and rises for events that either move the latent mean (novel spectral structure) or produce high reconstruction error (out-of-distribution input), or both.  The four per-VAE scores $s_0 \ldots s_3$ each correspond to a distinct spectral sub-band of the intensity spectrum, providing frequency-resolved anomaly information.

### 3.5 IRQ Structure

The classifier runs in a dedicated interrupt `IRQ_QTIMER4` (priority 128, below the DSP ISR) so that the DSP ISR can return before the classifier computation — which takes several hundred microseconds — completes.  The DSP ISR triggers the classifier ISR by posting the pending IRQ, passing a snapshot of $D$ and the full intensity matrix $I$.  The classifier ISR then runs the four forward+backward passes and pushes the result vector (header + latent means, and optionally the intensity matrix on signal frames) to the SD write queue.

---

## 4. Simulator

A Python simulator (`Python/simulator.py`) mirrors the complete firmware chain in a single `MicroPAM` class.  All constant names, variable names, weight array dimensions, and arithmetic are kept identical to the C source to make numerical comparison straightforward.  Float32 is used throughout.

### 4.1 Ocean Noise Model

The simulator uses the Wenz (1962) empirical model of ocean ambient noise as a realistic background source.  The noise power spectral density (PSD) in dB re 1 μPa²/Hz is the incoherent sum of four components:

| Component | Dominant range | Formula |
|---|---|---|
| Turbulence | < 10 Hz | $17 - 30\log_{10}(f_\mathrm{kHz})$ |
| Shipping | 10 Hz – 1 kHz | $20 + 12w + 20\log_{10}(f) - 30\log_{10}(f^2 + (15+4w)/10^4)$ |
| Wind (Knudsen) | 100 Hz – 50 kHz | $44 + 28\log_{10}(1+v^{0.75}) + 19\log_{10}(f) - 18\log_{10}(f^2 + 1/\phi^2)$ |
| Thermal | > 50 kHz | $-15 + 20\log_{10}(f_\mathrm{kHz})$ |

where $w \in \{0,1,2\}$ is the shipping density, $v$ is wind speed (m/s, converted from Beaufort sea state via $v = 27.6 (S/10)^{1.4}$), and $\phi = 2.78 + 0.14 v^{0.75}$.  The PSD is converted to a spectral amplitude filter applied in the frequency domain; four independent channels are generated (spatially uncorrelated, consistent with the ambient noise assumption).

### 4.2 Synthetic Signal Injection

To validate event detection and the per-VAE classification, a synthetic multi-step FM chirp signal is injected into the acquisition buffer every 100 processing frames.  The signal model is a power-law amplitude envelope with linear FM sweep:

$$s(t) = A \cdot (at)^b \cdot e^{-(at)^c} \cdot \cos\bigl(2\pi(f_0 + f_m t)t + \phi_0\bigr)$$

with $a = 5000$, $b = 2$, $c = 1.5$, $f_m = 15 \times 10^6$ Hz/s, and amplitude $A = 2^{30}$ counts.  The injection spans four consecutive DMA buffers (steps 0–3), each with a different starting frequency $f_0 = F_s(n/8 + 1/64)$ for step $n$, covering four distinct spectral regions.  Per-channel time delays $[0, 20, 10, 10]$ samples impose a directional signature that produces non-trivial intensity patterns $I_x, I_y, I_z$.

The four injection steps are designed to activate different VAE sub-bands preferentially, enabling a simple classifier: the VAE with the highest anomaly score above its noise-estimated threshold ($\mu_\mathrm{noise} + 3\sigma_\mathrm{noise}$) identifies the event type.

---

## 5. Model Persistence

Because the VAE adapts continuously to the local acoustic environment, the learned weights are valuable and should survive power interruptions.  On startup, `classifier_init()` calls `classifier_load()`, which reads the full model state — all weight matrices, biases, and background EMA accumulators — from `/VAE_model.dat` on the SD card root.  If the file is absent or has an invalid magic header (`0x56414531`), random Xavier initialisation is used instead.

Before any hibernation event (duty-cycle sleep or hour-window sleep), and at each new recording hour, `classifier_save()` writes the current model to the SD card.  If `/VAE_model.dat` already exists it is first renamed to `/VAE_backup/VAE_model_YYYYMMDD_HHMM.dat` (the `/VAE_backup/` subdirectory is created automatically on the first save), preserving a timestamped history of model snapshots organised in a dedicated folder.  The total model size is approximately 142 KB.

---

## 6. Output Format

In PROC_MODE 4, every processed frame produces a 24-word header in the SD write queue:

| Words | Content |
|---|---|
| [0] | Magic `0x55555555` |
| [1] | `millis()` firmware timestamp |
| [2] | `signal_flag` (1 = event detected, 0 = noise) |
| [3] | `detection_excess` = $D_\mathrm{snr} - \Theta$ (float) |
| [4–7] | `vae_detect[4]` per-VAE anomaly scores (float) |
| [8–23] | `vae_mu[16]` latent means, 4 per VAE (float) |

On signal frames an additional 3 × 512-word intensity matrix $I$ is appended atomically in the same queue block via `push_pair()`, enabling post-hoc spectral and directional analysis of detected events.

---

## 7. Discussion

### Background-only training as a design principle

The decision to train only on noise frames side-steps the core challenge of supervised edge classifiers: the absence of labelled training data in the field.  The VAE learns whatever the ambient environment sounds like during deployment — shipping noise, biological soundscape, flow noise — and treats departures as anomalies.  This is particularly appropriate for PAM applications where the target signals (cetacean vocalisations, fish sounds, anthropogenic events) are sparse and diverse.

### Spectral sub-band specialisation

Dividing the 512-bin intensity spectrum among four VAEs rather than training a single VAE on the full spectrum serves two purposes.  First, it reduces the per-VAE parameter count and computation to fit within the IRQ time budget ($\sim$600 μs at 192 kHz, 4 channels, 600 MHz CPU).  Second, sub-band specialisation means that events confined to a narrow frequency range (e.g. a tonal call) activate primarily one VAE, providing frequency localisation of the anomaly without explicit signal-processing steps.

### Limitations

The anomaly score $s_v$ is a product of two factors that can each fluctuate independently, so its absolute value depends on the stability of the background EMA.  Slow environmental transitions (e.g. diel changes in snapping shrimp intensity) may require tuning $\alpha$ to avoid the background tracker following the transition too slowly (false detections) or too quickly (missing the transition signal).  The 3σ threshold used in the simulator is post-hoc; a real-time adaptive threshold is a natural extension.

---

## 8. Conclusion

We have demonstrated a complete online VAE pipeline for acoustic anomaly detection on a Cortex-M7 microcontroller, operating in real time at 192 kHz with four microphone channels.  The system learns continuously from background noise, requires no labelled training data, persists its model across power cycles, and exports compact latent representations and anomaly scores for all processed frames to an SD card.  The Python simulator, which mirrors the firmware line-by-line and includes a physically motivated ocean noise model and synthetic signal injection framework, provides a validated development and testing environment for the algorithm before field deployment.

---

## 9. Post-Processing Analysis

A companion Python script `Python/vae_model_analysis.py` reads a folder of timestamped model snapshots produced by `classifier_save()` and generates a multi-page PDF report.  It parses the binary file layout (magic header + weight matrices in the same order as the firmware writer), extracts background EMA state (`recon_bg`, `mu_bg`), and computes Frobenius norms for W1 and W4.

```powershell
Python\.venv\Scripts\python.exe Python\vae_model_analysis.py <path-to-VAE_backup-folder>
```

The report contains:

| Page | Content |
|---|---|
| 1 | Summary text: files analysed, convergence metrics, key findings |
| 2 | Background reconstruction error `recon_bg` on a log scale — shows rapid convergence in the first hour |
| 3 | Frobenius norms of W4 (solid) and W1 (dotted) — W1 is effectively frozen; W4 adapts gradually |
| 4 | Mean `mu_bg` per VAE over time — reveals slow diel drift of the ambient background |
| 5 | `mu_bg` by latent dimension for VAE 0 — shows which dimensions encode the dominant spectral features |

The script is self-contained (numpy + matplotlib only) and can be run on any machine without the firmware build environment.

---

*microPAM V4 — Copyright © 2026 Walter Zimmer. Released under the MIT License.*

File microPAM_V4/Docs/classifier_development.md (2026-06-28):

# microPAM_V4 — Classifier Development Summary

**Date:** 2026-06-28  
**Branch:** main  
**Version:** 4.3.0

---

## 1. Overview

This document summarises the development of the online VAE-based signal classifier
for microPAM_V4, carried out entirely in the Python simulator (`Python/simulator.py`)
with firmware changes applied once a configuration was validated.

The goal is to detect transient acoustic events (e.g. bat echolocation chirps) in
real-time on a Teensy 4.1, classify which frequency sub-band they occupy, and log
the result without interrupting recording.

---

## 2. Processing Chain (PROC_MODE 4)

```
acq_buffer (int32, 2048 samples, 4-ch interleaved)
  └─ spectrum_apply()     50%-overlap RFFT per channel → Z[512, 4, 2]
  └─ intensity_apply()    Im(conj(Za)·Zb) cross-correlations → I[512,3], D[512]
  └─ detection_apply()    exponential background tracking → Dsnr
  └─ classifier_apply()   4 parallel VAEs → vae_mu[16], vae_detect[4]
  └─ queue.push()         16 float32 latent means → SD card (.vae file)
```

**Key constants**

| Symbol | Value | Meaning |
|---|---|---|
| FSAMP | 192 000 Hz | Sample rate |
| NBUF_ACQ | 2048 | Samples per DMA buffer (4 ch × 512) |
| NSAMP | 512 | Samples per channel per buffer |
| NFFT | 1024 | FFT length (50% overlap) |
| DETECT_THR | 3.0 | SNR threshold for signal detection |
| DETECT_ALPHA | 0.01 | Background EMA coefficient |
| VAE_NVAE | 4 | Number of parallel VAEs |
| VAE_QSAMP | 128 | D[] bins per VAE (freq sub-band) |
| VAE_H1 | 32 | Hidden layer width |
| VAE_LAT | 4 | Latent dimensions per VAE |
| VAE_LAT_TOTAL | 16 | Total exported latent means |
| LR | 1e-4 | SGD learning rate |
| BETA | 1e-3 | KL regularisation coefficient |

**VAE frequency band mapping**

| VAE | D[] bins | Frequency range |
|-----|---|---|
| VAE0 | 0–127 | 0–24 kHz |
| VAE1 | 128–255 | 24–48 kHz |
| VAE2 | 256–383 | 48–72 kHz |
| VAE3 | 384–511 | 72–96 kHz |

---

## 3. VAE Architecture

Each of the 4 VAEs is an independent online VAE with architecture:

```
Q=128 → ReLU(W1@x + b1) → (mu, lv) → z = mu + eps·exp(0.5·lv)
      → ReLU(W3@z + b3) → W4@h3 + b4 → recon[Q]
```

- Loss: MSE(recon, D_q) + β·KL,  KL = 0.5·Σ(exp(lv) + mu² − 1 − lv)
- Weights initialised Xavier uniform; biases zero.
- W1[4][32][128] and W4[4][128][32] placed in DMAMEM (128 KB total).
- All other weights in RAM1 (~17 KB).

---

## 4. Noise-Gated Training

**Key design decision:** The VAE is trained **only on noise frames** (Dsnr < DETECT_THR).
On signal frames the backward pass is skipped; only the forward pass runs to extract mu.

This prevents the signal events from corrupting the noise background model that
the VAE latent space encodes.

**Implementation (C — classifier.cxx):**
```c
bool signal_frame = (Dsnr_buf >= DETECT_THR);
for (int v = 0; v < 4; v++) {
    vae_forward(v, D_q);
    if (!signal_frame) vae_backward(v, D_q);
}
if (signal_frame) {
    for (int k = 0; k < VAE_LAT_TOTAL; k++) vae_mu_signal[k] += vae_mu[k];
    vae_mu_signal_count++;
}
```

`Dsnr` is passed from `dsp_apply()` to `classifier_trigger()` as an extra argument
and stored in `Dsnr_buf` for the async ISR to read.

**Exported globals (readable from .ino):**

| Variable | Type | Description |
|---|---|---|
| `vae_mu[16]` | float[] | Current-frame latent means |
| `vae_mu_signal[16]` | float[] | Accumulated means on signal frames |
| `vae_mu_signal_count` | uint32 | Number of accumulated signal frames |

The `.ino` monitor prints and resets `vae_mu_signal / count` every second.

---

## 5. Per-VAE Detection Score

**Simulator-only** (`Python/simulator.py`). No firmware equivalent.

Each VAE maintains a noise background EMA for both mu and reconstruction error,
updated only on noise frames (same gate as training):

```python
# noise frame only:
mu_bg[v]   += DETECT_ALPHA * (mu_v   - mu_bg[v])
recon_bg[v] += DETECT_ALPHA * (err_v  - recon_bg[v])

# every frame:
mu_dev      = ||mu_v - mu_bg[v]||₂
recon_ratio = recon_v / recon_bg[v]
vae_detect[v] = mu_dev × recon_ratio
```

`vae_detect[v]` is large when the current frame's latent representation has moved
away from the noise cluster **and** the reconstruction error has increased —
i.e. both components must agree that something unusual is present.

---

## 6. Hyperparameter Sweep Results

Sweep over 50 000 iterations per configuration (noise_amp = 2²⁵, USE_SYNTH_SIGNAL=True):

| Option | VAE_H1 | VAE_LAT | BETA | LR | max\|sep\| σ | mean\|sep\| σ |
|---|---|---|---|----|---|---|
| Baseline | 32 | 2 | 1e-3 | 1e-4 | 2.64 | 0.53 |
| Lower BETA=1e-4 | 32 | 2 | 1e-4 | 1e-4 | 2.62 | 0.52 |
| Lower BETA=1e-5 | 32 | 2 | 1e-5 | 1e-4 | 2.62 | 0.52 |
| **LAT=4** | 32 | **4** | 1e-3 | 1e-4 | **17.48** | **2.36** |
| Wider H=64 | 64 | 2 | 1e-3 | 1e-4 | 5.04 | 1.00 |
| Higher LR=1e-3 | 32 | 2 | 1e-3 | 1e-3 | 1.16 | 0.28 |
| LAT=4 + BETA=1e-5 | 32 | 4 | 1e-5 | 1e-4 | 17.48 | 2.35 |
| LAT=4 + H=64 | 64 | 4 | 1e-5 | 1e-4 | 24.13 | 2.45 |

**Selected: VAE_LAT=4, VAE_H1=32** — LAT=4 gives the largest gain; H=64 is excluded
because W1+W4 at H=64 requires 256 KB DMAMEM, overflowing the Teensy 4.1 RAM2
(only 12 KB headroom). VAE_LAT_TOTAL becomes 16 (was 8). BETA and LR unchanged.

---

## 7. VAE Input Selection

Three options tested over 100 000 iterations:

| Input | VAE0 recall | VAE1 recall | VAE2 recall | VAE3 recall | Notes |
|---|---|---|---|---|---|
| **Intensity D[]** | **83.7%** | **70.8%** | **47.4%** | **44.8%** | Best overall |
| Mean spectrum (all ch) | 86.5% | 49.9% | 48.8% | 51.6% | Mixed |
| Spectrum ch0 only | 56.4% | 44.5% | 40.7% | 43.0% | Worst |

**Selected: intensity D[]** — cross-channel intensity suppresses uncorrelated noise
(random inter-channel phases cancel), giving the VAE a higher-SNR input than any
single-channel or averaged power spectrum.

---

## 8. Confusion Matrix (final configuration, 100 000 iterations)

VAE input: intensity D[], VAE_LAT=4, noise-gated training, noise_amp=2²⁵.

```
GT \ Pred    noise    VAE0    VAE1    VAE2    VAE3
--------------------------------------------------
noise        89762    1865    1817    1826     733    (recall 93.5%)
VAE0           153     837       5       5       0    (recall 83.7%)
VAE1            13     279     707       0       0    (recall 70.8%)
VAE2             1       0     524     474       0    (recall 47.4%)
VAE3            21       0       1     529     448    (recall 44.8%)
```

**Combined detector** (sum of vae_detect across 4 VAEs, threshold = noise_mean + 3σ):
- True positive rate: **93.6%** (3747 / 4003 signal frames)
- False positive rate: **0.80%** (770 / 95 997 noise frames)

---

## 9. Timing Structure of VAE Detection

The synthetic chirp sweeps 80 kHz in one 2.67 ms buffer, so all 4 VAE frequency
bands receive energy simultaneously. However, because each SYNTH step starts at a
different f0, the peak vae_detect for each VAE occurs at a different frame:

```
SYNTH step 0 (f0=  3 kHz) → VAE0 peaks at event frame + 0..1
SYNTH step 1 (f0= 27 kHz) → VAE1 peaks at event frame + 1..2
SYNTH step 2 (f0= 51 kHz) → VAE2 peaks at event frame + 2..3
SYNTH step 3 (f0= 75 kHz) → VAE3 peaks at event frame + 3..4
```

The 1-frame sequential offset between VAEs is **accepted as part of the design** —
it reflects the physical sweep of the chirp through frequency and is not a defect.
The resulting confusion between adjacent VAEs (VAE2↔VAE3) is a known limitation.

---

## 10. Why VAE0 Scores Lower Than VAE1–3

The directional intensity estimator computes:

```
D[k] = ||Im(conj(Za)·Zb)||  for channel pairs (a,b)
```

At low frequencies (VAE0: 0–24 kHz), inter-channel delays [0, 20, 10, 10] samples
produce small phase differences (Δφ = 2π·f·Δt ≪ 1), making Im(conj(Za)·Zb) ≈ 0
even for a coherent signal. VAE0 is therefore in the directional sensitivity null.
This is physically correct for the given array geometry — it is not a bug.

Mean D excess per band on signal frames:
- VAE0 (0–24 kHz): 0.0010 (4× lower)
- VAE1 (24–48 kHz): 0.0041
- VAE2 (48–72 kHz): 0.0040
- VAE3 (72–96 kHz): 0.0030

---

## 11. Files Modified / Created

| File | Change |
|---|---|
| `src/classifier.h` | VAE_LAT 2→4; added vae_mu_signal[], vae_mu_signal_count; updated classifier_trigger signature |
| `src/classifier.cxx` | Noise-gated training; Dsnr_buf; vae_mu_signal accumulation |
| `src/process.cxx` | Passes Dsnr to classifier_trigger |
| `microPAM_V4.ino` | Prints vae_mu_signal/count in monitor loop; resets after print |
| `Python/simulator.py` | Full processing chain mirror; noise-gated VAE; vae_detect; per-frame log; confusion matrix; OceanNoise class |
| `Python/viewer.py` | Time-series viewer (Dsnr + vae_detect); confusion matrix heatmap |
| `Python/synth_spectrogram.py` | Spectrogram of synthetic chirp signals per step and channel |
| `Python/decompress.py` | Decoder for compressed .bin/.spc/.int files |
| `Python/micropam_reader.py` | File reader dispatching by PROC_MODE |
| `Python/sim_log.npz` | 100 000-frame simulation log (not versioned) |

---

---

## 13. Realistic Ocean Noise Model (Wenz 1962)

### 13.1 Background

Flat white Gaussian noise is an unrealistic acoustic background for ocean deployments.
The `OceanNoise` class added to `Python/simulator.py` replaces the white noise
generator with spectrally shaped noise whose PSD follows the empirical Wenz (1962)
model, parameterised by **ship density** (shipping traffic level) and **sea state**
(Beaufort scale).

Reference: <https://www.passiveacoustics.org/2025/03/16/ambient-noise/>

### 13.2 Wenz Model Components

The total noise PSD (dB re 1 μPa²/Hz) is the linear (power) sum of four components:

| Component | Equation (f in kHz) | Dominates |
|---|---|---|
| Turbulence | `NL_turb = 17 − 30·log₁₀(f)` | < 10 Hz |
| Shipping | `NL_ship = 20+12w + 20·log₁₀(f) − 30·log₁₀(f²+(15+4w)/10⁴)` | 10 Hz – 1 kHz |
| Wind/Knudsen | `NL_surf = 44+28·log₁₀(1+v^0.75) + 19·log₁₀(f) − 18·log₁₀(f²+1/(2.78+0.14v^0.75)²)` | 100 Hz – 50 kHz |
| Thermal | `NL_therm = −15 + 20·log₁₀(f)` | > 50 kHz |

Sea state S (Beaufort 0–9) converts to wind speed: `v = 27.6·(S/10)^1.4` m/s.
Ship density w ∈ {0, 1, 2} = light / moderate / heavy traffic.

### 13.3 Implementation (`OceanNoise` class)

```python
noise_src = OceanNoise(ship_density=1, sea_state=3,
                       rms_counts=2**25, rng=rng)
acq_buffer = noise_src.generate()   # int32, shape (NBUF_ACQ,), channels interleaved
```

The class pre-computes the amplitude spectrum at `__init__` time (one rfft over NSAMP
bins), then per `generate()` call produces independent per-channel coloured noise:
white noise → FFT → multiply by amplitude filter → IFFT → scale to `rms_counts` RMS.

Module-level switches in `simulator.py`:

| Constant | Default | Meaning |
|---|---|---|
| `USE_OCEAN_NOISE` | `True` | Enable Wenz noise model |
| `SHIP_DENSITY` | `1` | 0=light, 1=moderate, 2=heavy |
| `SEA_STATE` | `3` | Beaufort 0-9 |
| `NOISE_RMS_COUNTS` | `2**25` | Overall RMS in int32 counts |

### 13.4 Performance Comparison (100 000 frames each)

All runs: `NOISE_RMS_COUNTS = 2²⁵`, `USE_SYNTH_SIGNAL = True`, `VAE_LAT = 4`.

#### White noise (baseline)

```
GT \ Pred    noise     VAE0     VAE1     VAE2     VAE3
------------------------------------------------------
noise        89762     1865     1817     1826      733   recall=93.5%
VAE0           153      837        5        5        0   recall=83.7%
VAE1            13      279      707        0        0   recall=70.8%
VAE2             1        0      524      474        0   recall=47.4%
VAE3            21        0        1      529      448   recall=44.8%

Detector: TPR=95.3%   FPR=6.50%
```

#### Ocean noise — moderate (ship_density=1, sea_state=3, wind=5.1 m/s)

```
GT \ Pred    noise     VAE0     VAE1     VAE2     VAE3
------------------------------------------------------
noise        90365     1426     1767     1692      753   recall=94.1%
VAE0           522      459        9       10        0   recall=45.9%
VAE1             3      178      818        0        0   recall=81.9%
VAE2             0        2      590      407        0   recall=40.7%
VAE3             0        1        0      502      496   recall=49.6%

Detector: TPR=86.9%   FPR=5.87%
```

#### Ocean noise — heavy/rough (ship_density=2, sea_state=6, wind=13.5 m/s)

```
GT \ Pred    noise     VAE0     VAE1     VAE2     VAE3
------------------------------------------------------
noise        90280     1506     1771     1692      754   recall=94.0%
VAE0           608      369       10       13        0   recall=36.9%
VAE1             4      173      822        0        0   recall=82.3%
VAE2             0        3      545      451        0   recall=45.1%
VAE3             0        1        0      539      459   recall=45.9%

Detector: TPR=84.7%   FPR=5.96%
```

#### Summary

| Condition | TPR | FPR |
|---|-----|-----|
| White noise | **95.3%** | 6.50% |
| Ocean, ship=1, SS=3 | 86.9% | 5.87% |
| Ocean, ship=2, SS=6 | 84.7% | 5.96% |

### 13.5 Analysis

**VAE0 (0–24 kHz) degrades strongly under ocean noise.**
The shipping component of the Wenz model dominates 10 Hz – ~1 kHz and rolls off
as `~f⁻²` up to ~24 kHz, exactly overlapping the VAE0 band. The VAE background
model adapts to elevated, spectrally structured low-frequency noise, reducing its
ability to separate the chirp from natural fluctuations.

| VAE | White noise signal/noise ratio | Ocean SS3 ratio | Ocean SS6 ratio |
|-----|---|---|---|
| VAE0 | 8.2× | 4.5× | 3.3× |
| VAE1 | 14.8× | **83.5×** | **84.2×** |
| VAE2 | 14.4× | **110.3×** | **121.6×** |
| VAE3 | 7.2× | 15.2× | 15.3× |

**VAE1 and VAE2 (24–72 kHz) improve dramatically under ocean noise.** The Wenz
spectrum rolls off sharply above ~5 kHz (shipping gone, thermal not yet dominant),
leaving mid-high frequencies quieter than white noise. The VAE background EMA
settles at a lower level, producing a larger relative signal excursion and higher
signal-to-noise ratios (83–121×).

**FPR is slightly lower under ocean noise** (6.5% → ~5.9%) for the same reason:
a stable, predictable background in the mid-high bands produces tighter noise
distributions and more accurate per-VAE thresholds.

**Practical implication:** for real ocean deployments with significant shipping traffic,
VAE0 sensitivity will be reduced and may require a higher-SNR source signal, a longer
detection integration window, or a dedicated low-frequency background model.

---

## 12. Known Limitations and Open Questions

1. **VAE2/VAE3 recall ~45–47%** — caused by the 1-frame timing ambiguity between
   adjacent SYNTH steps. Accepted by design.
2. **False alarm rate 0.80% per frame** — at 192 kHz / 512 samples per frame =
   375 frames/s, this gives ~3 false alarms per second. May need a 2-of-N gate
   for practical deployment.
3. **VAE0 low sensitivity** — directional null at low frequencies for the given
   array geometry. Could be addressed by a different array configuration or by
   using the spectrum instead of intensity for VAE0 only.
4. **Noise amplitude sensitivity** — detection requires noise_amp ≤ 2²⁶ for the
   synthetic chirp to exceed DETECT_THR. Real-world SNR must be verified on hardware.
5. **Online SGD instability at LR=1e-3** — confirmed in sweep; keep LR=1e-4.

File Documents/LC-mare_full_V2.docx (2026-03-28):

# LC-MARE

Walter MX Zimmer

21-03-2026

## Objective

Aim of the low-cost science-grade marine autonomous acoustic recorder (LC-MARE) is to provide a cost-effective solution to access and record underwater sound. The implementation should be low-cost but without limitations on sound quality.

The project is completely open source, and all information may be found on GitHub (https://github.com/WMXZ-EU/LC-MARE).

## Concept

The implementation should be low-cost but without constraints on scientific data quality.

An underwater autonomous recorder consists of four major components:

- Hydrophone
- Recording electronics
- Batteries
- Pressure housing

While the electronic components are nowadays easily available and relatively cost-effective, hydrophones and pressure housing are notoriously expensive but important components, as they determine the scientific quality of the collected data. Therefore, it is essential to define upfront the use-case and decide on:

- Minimal useful acoustic bandwidth needed for the expected scientific results as this defines the size of the hydrophone.
- Maximal deployment depth must be considered for the hydrophone selection and pressure housing material and construction.
- Endurance of the recorder, as this in connection with the power consumption of the electronics determines the size of the required battery pack.

#### Acoustic bandwidth :

The acoustic bandwidth of the recorder is a significant cost factor. It seems clear that use cases that are only concerned with signals, say below 5 kHz, the use of hydrophones and recorder bandwidth of 100 kHz or more do not add to the relevance of the acoustic data. Using an acoustic bandwidth of 20 to 40 kHz and a sampling frequency of 48 kHz are more than adequate. However, use cases where dolphin or beaked whale echolocation clicks are the signals of interest, broadband hydrophones (i.e. bandwidth >100kHz) and sampling frequencies of 192 kHz are asked for.

As sampling frequencies and acoustic bandwidth are related, so does the required storage increase with the sampling frequency. As a side-effect increased sampling frequency requires also extended memory to buffer the recorded data during the archiving process.

#### Deployment depth;

The deployment depth of the recorder can have a significant impact on its implementation, especially if the recorder contains removable components, like microSD cards, batteries or connectors, or movable components, like buttons. In these cases, the recorder housing must contain air and therefore withstand a pressure difference that corresponds to the deployment depth. Only recorders without (re)movable components can be filled with oils or resins.

Not only electronic containers must withstand ambient pressure, but also hydrophones that to achieve best performance must contain air. From the two typical hydrophone forms, cylindrical and spherical, only the spherical form is designed for great deployment depth well beyond 1000 m, while cylindrical hydrophones may crash well below 1000 m. Only special hydrophone encapsulation may increase the hydrophone survival depth to well above 1000 m.

#### Recorder endurance:

As with all autonomous systems the sound recorder must contain its own power source, which in most cases is provided in form of one or more battery packs. To assess the endurance of the recorder the consumption must also be known. If continuous recording is desired, then the recorder consumption is the limiting factor, and the size of the power source is a consequence of the recording time. If duty-cycling of the recording is acceptable, then the recorder endurance is a consequence of battery capacity, power consumption and recording schematic.

## Aim and use cases of LC-MARE

The envisioned use cases are defining the required characteristics of the LC-MARE autonomous recorder, and LC-MARE is aimed at generation of science-grade marine acoustic data that support

- entry-level scientific research (e.g. for undergraduate and graduate students)
- environmental monitoring of coastal marine areas (being protected or not)
- marine bioacoustics in STEM education

It is envisioned that LC-Mare

- is used up to a recorder depth of 100 m.
- is recording up to 50 kHz bandwidth.
- Is continuously recording acoustic data up to 30 days.
- may be calibrated to allow comparisons and exchanges of data.

## Cost factors

In addition to the envisioned use cases, the convenience of the LC-MARE implementation is determined by its complexity and cost factors. If the implementation is too complex or too costly a custom implementation may not be convenient.

There are different levels of complexity and cost factors.

- Commercially available components:
- Piezo ceramic tubes
- Programmable recording system (MCU, microSD card, RTC)
- Pressure housing components.

These components are typically produced in quantities, and no major cost saving is anticipated.

- Specific made components:
- Analog amplifier
- Analog-digital conversion
- Base board (to avoid cabling)

These components are specific made for LC-MARE and the ‘set-up’ costs are usually higher than the component costs. Therefore, only the production of multiple units (say 50 to 100+units) reduces the price-tag per unit to nearly the component costs.

- Custom made components:
- Hydrophone construction
- Pressure vessel construction.
- Mounting frame

Depending on the use cases and individual skills these components may be built by the interested users, whereby the hydrophone construction is the most demanding task and may be appropriate only for experienced users. It is expected that, while DIY is possible, for most users the hydrophones are constructed by specialized businesses.

The construction of pressure vessels depends again on the use-cases and assuming shallow water applications (recorder depth <100 m) user build pressure vessels are feasible using pressure-rated PVC tubes and fittings.

## Implementation

### Hardware LC-Mare V2

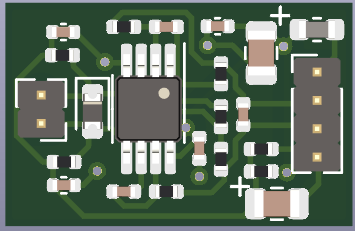
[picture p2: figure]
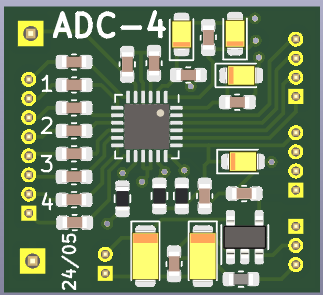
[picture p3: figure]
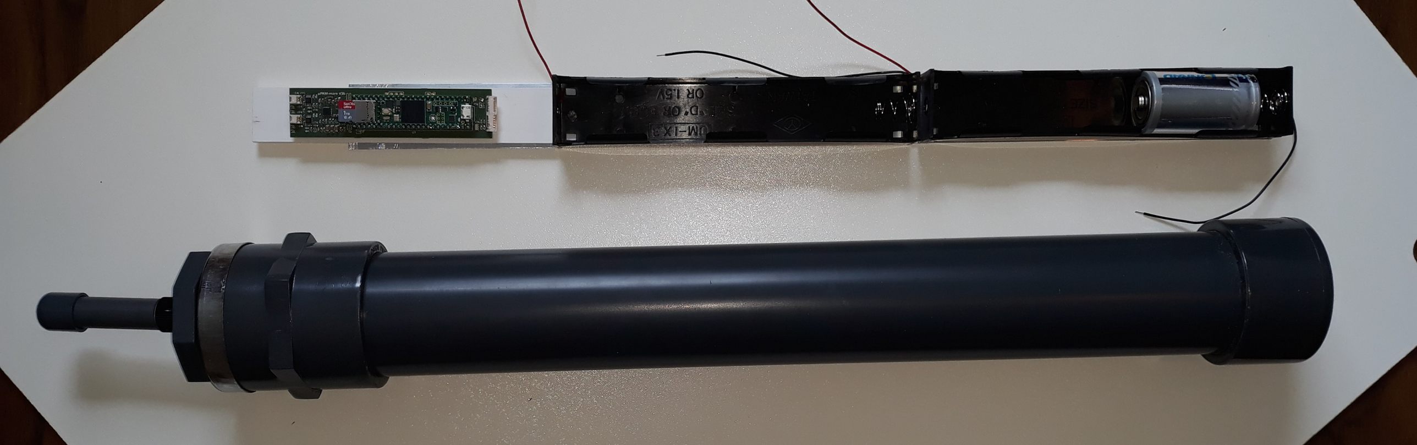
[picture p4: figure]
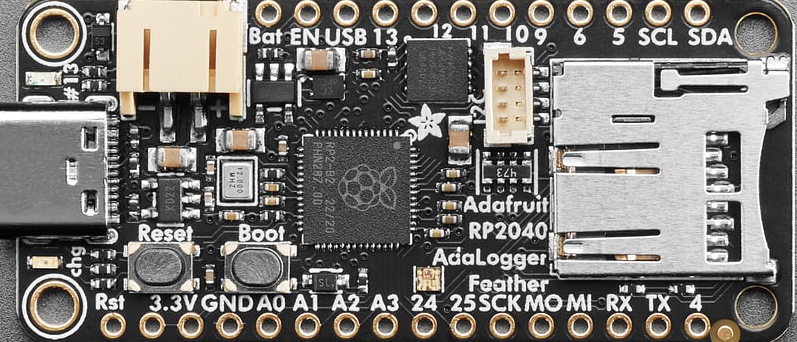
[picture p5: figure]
Overhead shot of black, rectangular datalogging board.
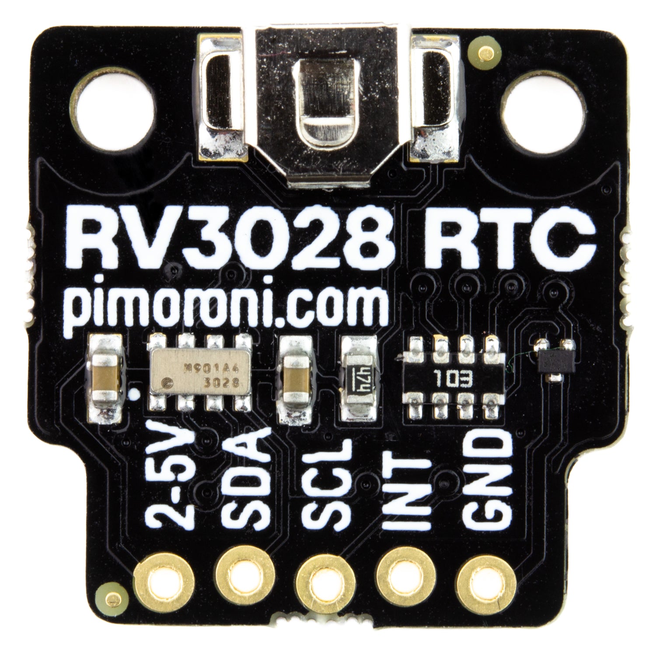
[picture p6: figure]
An image of RV3028 Real-Time Clock (RTC) Breakout

Pre-amp

Gain 21

AD8656

25 mW

ADC

4-chan

TLV320ADC6140

50 mW

Recorder

MCU: RP2040

uSD storage

RV3028 RTC

80 mW @ fs=96 kHz

Power+Container

144 Wh Battery

930 h Endurance @ 155 mW

16 bar max pressure

Figure 1: LC-Mare V2 Hardware components.

The components of a first LC-MARE prototype are shown in Figure 1. The electronics is composed of multiple components to facilitate easy replacement of components, if deemed necessary.

Length and diameter of the pressure tube are determined by the size of the battery holders and resulted to 500 x 63 mm for a 6 D-Cell battery pack. Using additional fittings and tubes, the power supply can easily be extended by adding additional four battery containers.

The pressure tube and fittings are 16 Bar rated PVC tubes, commercially made for water pipe constructions, e.g. for swimming pools.

### Software

The software is using standard C/C++ code and by being compatible with the Arduino infrastructure it is easily maintained, modified and downloaded to the microcontroller of the LC-MARE. The few parameters that are expected to be modified at sea may be provided using a terminal program, a python GUI or by a file on the microSD card that can be prepared prior to the at-sea activity.

# Recorder

Figure 2: LC-Mare August 2024 version.

## Implementation details

The LC-MARE implementation will be open source and hard and software implementation will be published at GitHub - WMXZ-EU/LC-MARE: low-cost marine acoustic recorder (https://github.com/WMXZ-EU/LC-MARE)

### Hydrophone

Idea of a custom hydrophone

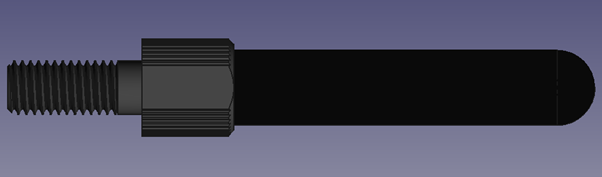
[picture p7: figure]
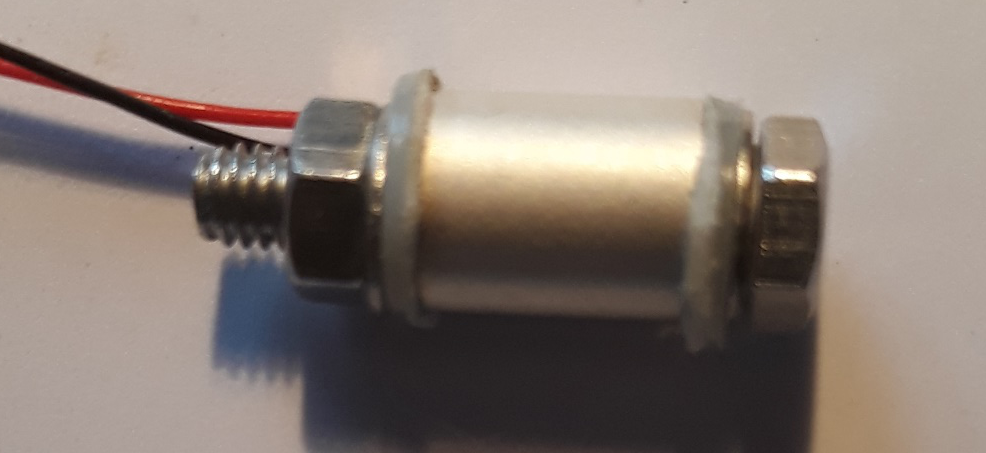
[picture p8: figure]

Figure 3: Custom made hydrophone using piezo-ceramic tubes

This Hydrophone consists of three components: Cylindrical piezo-ceramic tube, BlueRobotics penetrator, and polyurethane rubber. The hydrophone is at some distance from the penetrator to reduce acoustic interference of the pressure container. The use of BlueRobotics penetrators facilitates the changes of hydrophones and pressure containers.

As Endcapping of piezo-ceramic tubes is somewhat demanding it may be necessary to obtain ready-to-use COTS hydrophones, which are then mounted onto BlueRobotics penetrators as shown in Figure 4

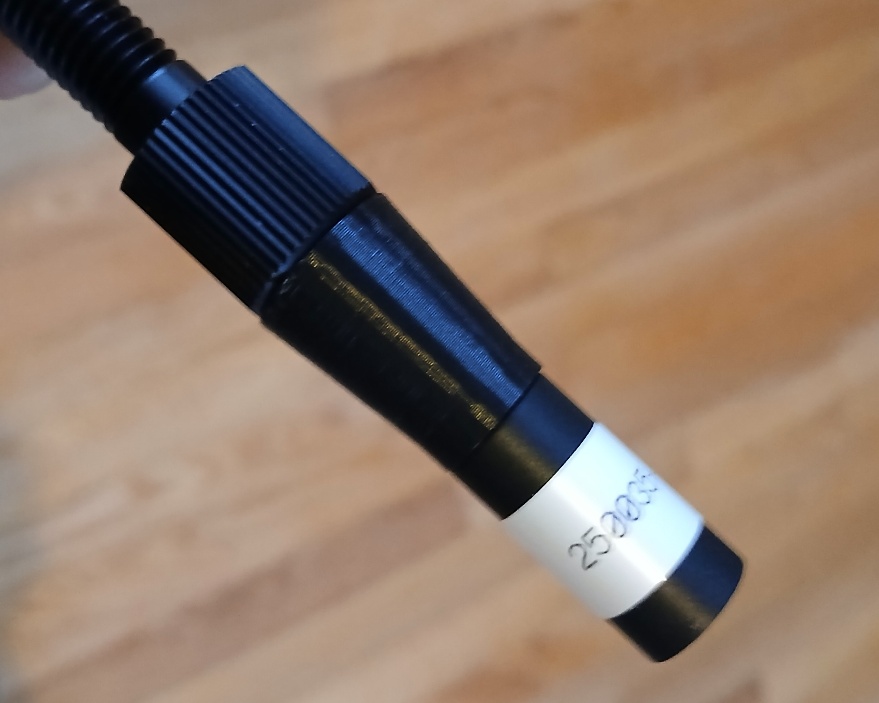
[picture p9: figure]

Figure 4: LC-Mare hydrophone SQ-17 potted onto BlueRobotics penetrator.

### Pressure Container

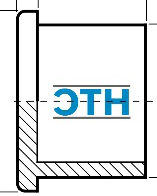
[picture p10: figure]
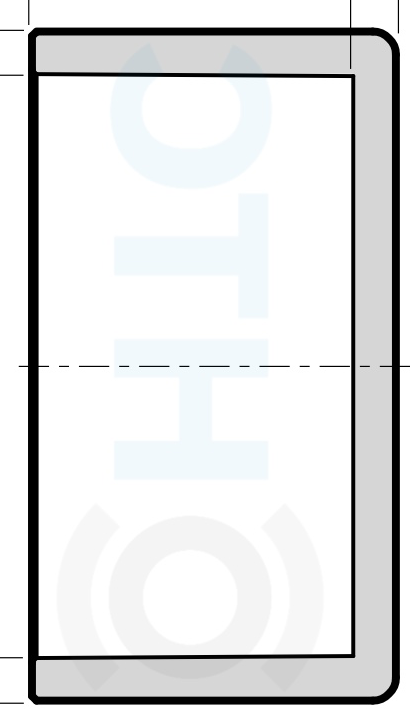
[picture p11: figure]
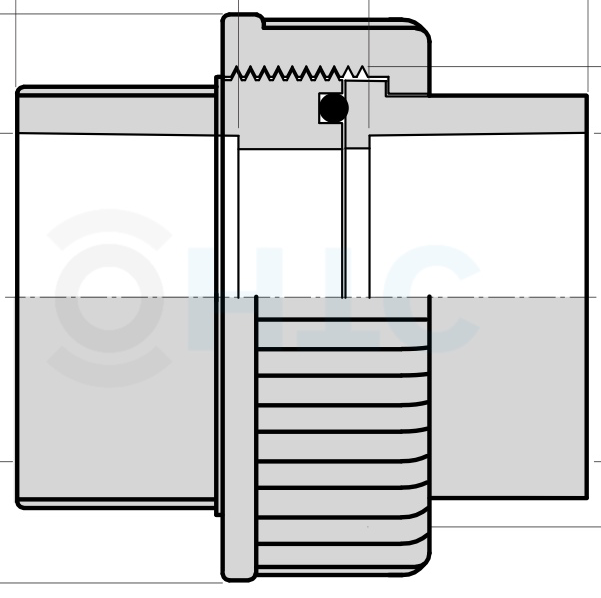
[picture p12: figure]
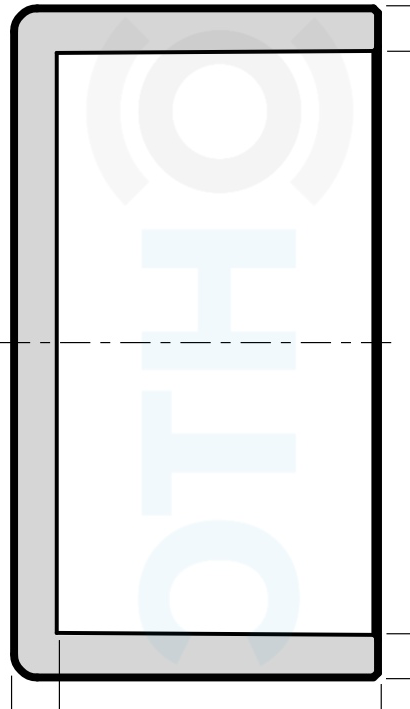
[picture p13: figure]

Endcap (A)

ID 63 mm

Tube 500 mm

OD 63 mm

Endcap (C)

OD 50 mm

Endcap (B)

ID 50 mm

OD 63 mm

Union

ID 63 mm

Figure 5: Pressure container components.

The pressure container consists of 5 components a 500 mm long tube, one union, 3 Endcaps with different diameters. To connect the hydrophone a 10 mm hole will be drilled in the middle-sized endcap (Endcap (B). The PVC-U components are rated with PN16 and should withstand 16 bar internal pressure. It is expected that they also withstand 15 Bar external pressure, which corresponds to a water depth 150 m. The PVC-U tubes and fittings are purchased from an online store (pcv-welt.de) but may be found in hardware stores.

### Electronics

For the electronics we have following components

#### Pre-amplifier

The pre-amplifier is a differential-to-differential voltage amplifier, the Spice simulation is shown next:

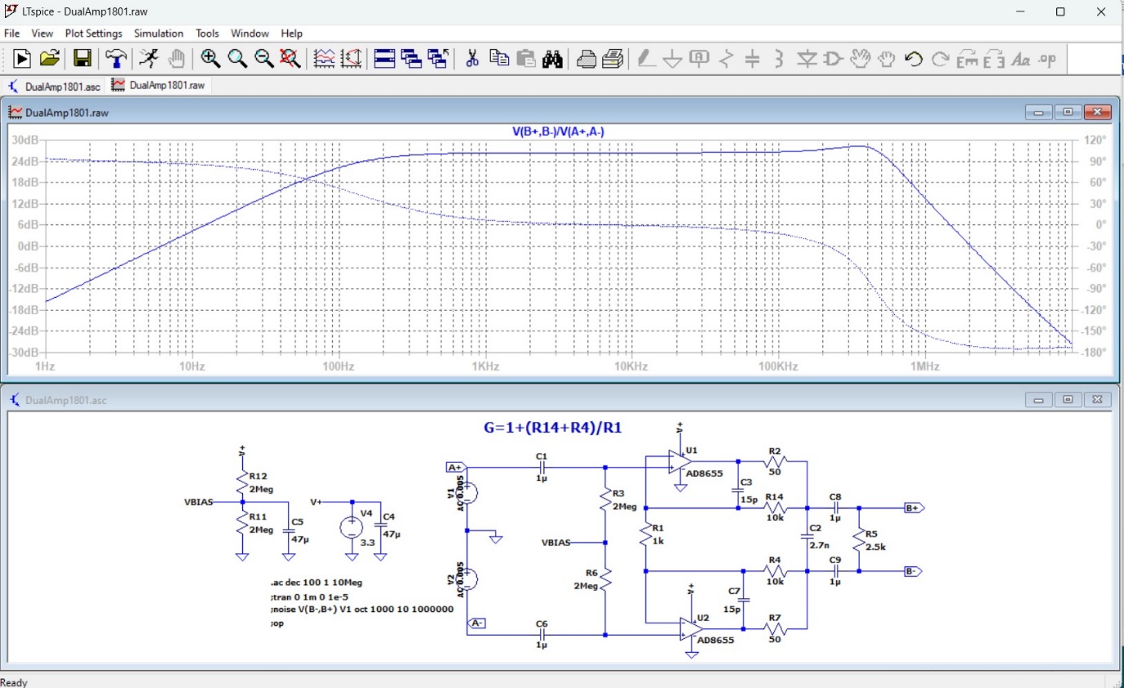
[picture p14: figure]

Gain is controlled effectively by the resistor R1. There is still some gain increase at 400 kHz, which can be removed by increasing the feedback capacitors C3, C7 somewhat. The selected OP-AMPS are of CMOS type with 2.7 nV/sqrt(Hz) noise voltage each.


Figure 6: Preamplifier

A more lower noise pre-amplifier with FET and ultra-low noise bipolar amplifier would be a possible alternative and is in development.

#### Analog Digital Conversion

The ADC is based on the Texas Instruments TLV320ADC6140 chip and implements the circuitry of the datasheet.

The ADC features 4 differential input channels each of which can be amplified up to 40 dB. A dedicated LDO regulator provides 3.3V for the analog circuitry.

Sampling frequencies can be up to 768 kHz for a single channel, 384 kHz for two channels and 192 kHz for all four channels. Bit depth is 24 bits.

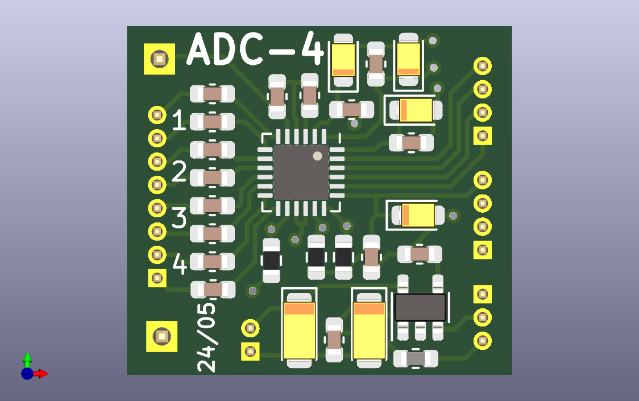
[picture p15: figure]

Figure 7: Analog-digital-converter

### Putting it all together

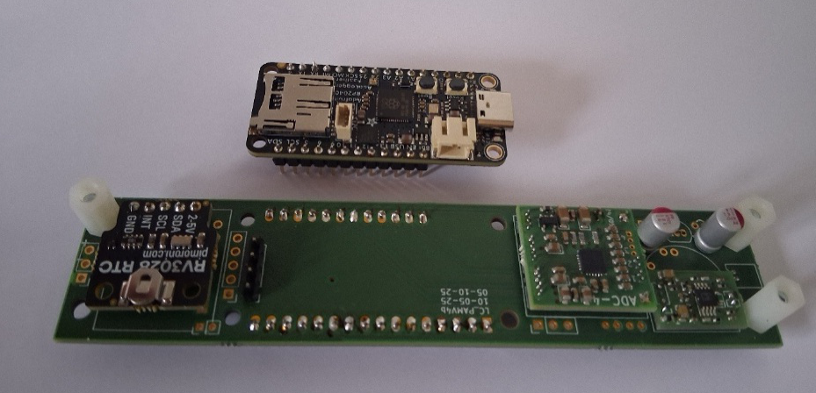
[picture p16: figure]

Figure 8: All components and connecting base board

The final electronics board features 1 pre-amp, a 4-channel ADC, an Adafruit Feather Adalogger Rp2040 and a RV3028 RTC.

## Software

Fully programmed with C/C++ code but can be compiled and downloaded within the Arduino ecosystem or using Makefiles.

All software is available on Github (https://github.com/WMXZ-EU/LC-MARE).

Data storage is using ExFat filesystem and after removing the disk, the data can be accessed directly by the PC. This allows also to store/edit configuration files on the disk ahead of closing the pressure container.

### GUI

The following Python based GUI shows some of the parameters that may be retrieved and stored and may be the basis for a Custom GUI.

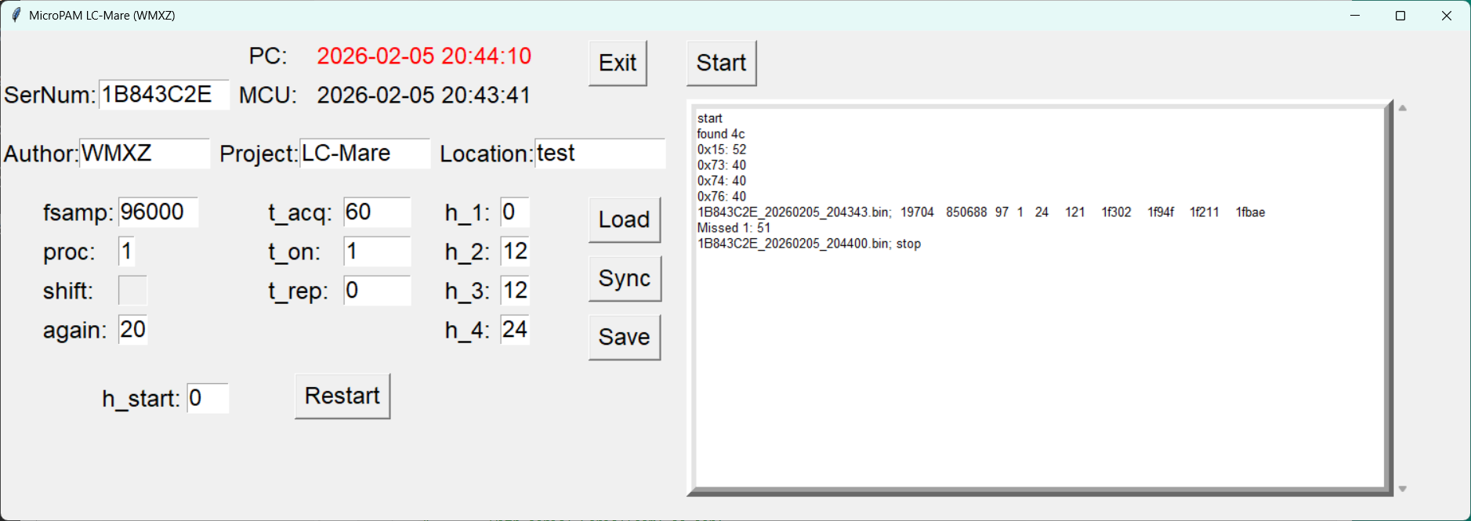
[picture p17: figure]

This GUI shows some parameters that are used for controlling the functionality of LC-MARE. Gray-ed fields are de-activated as not in use in the actual implementation.

The Form will be populated with the ‘Load’ button. The ‘Sync’ button will synchronize the RTC with the PC time. Parameters will be downloaded to MCU using the ‘Save’ button.

The start button will start the acquisition process and will display the messages from the MCU. At the same time the button changes to a Stop button to stop the acquisition process.

The Restart button will reboot the connected MCU. If the h_start value is zero, then the MCU will reboot immediately. Any value >0 will delay the reboot to the next full hour. For example, for a value of 1 the MCU will reboot at the next full hour, with a value of 5 the MCU will reboot at the last full hour in the next 5 hours.

Parameters shown in GUI:

- fsamp: sampling frequency in Hz
- proc: online processing: 0 wav file; 1: integer loss-less compression.
- shift: in case of compression indicates the number of lower bits that are to be ignored (deactivated in screenshot)
- again: analog gain in dB in ADC
- t_acq: length of files in s
- t_on: length of acquisition block in s
- t_rep: time in s between starts of acquisition blocks in s (0 means continuously)
- h_1: start hour of first acquisition period
- h_2: end of first acquisition period
- h_3: start of second acquisition period
- h_4: end of second acquisition period
- h_start: reboot delay in hours (0 immediately, 1 next full hour, etc)

In above GUI image, the acquisition timing parameters are set for continuous recording.

# Mounting system

The electronic and battery packs are mounted onto an aluminium plate (35x50x2) by means of double-sided adhesive tapes. To separate electronics from conducting aluminium an additional PVC plate is added. The mounting plate is attached to hydrophone penetrator using an aluminium U frame. All components are from the local hardware store.

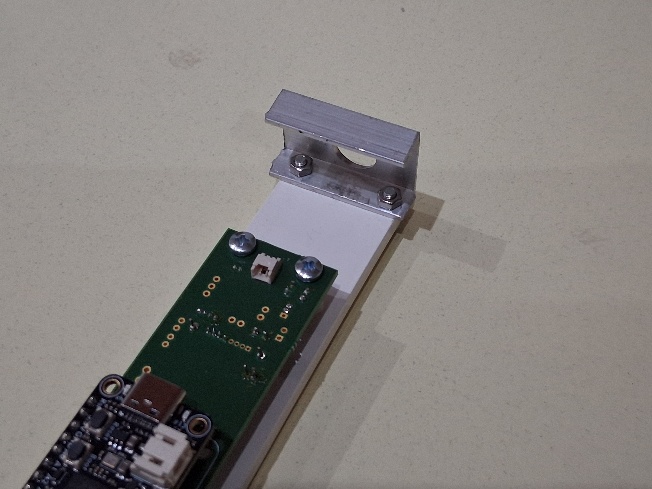
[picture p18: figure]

## Alternative mounting

To avoid the mounting of the recorder components (electronic and batteries), alternative methods can be used. This may also be necessary if the penetrator is too short to accept two nuts.

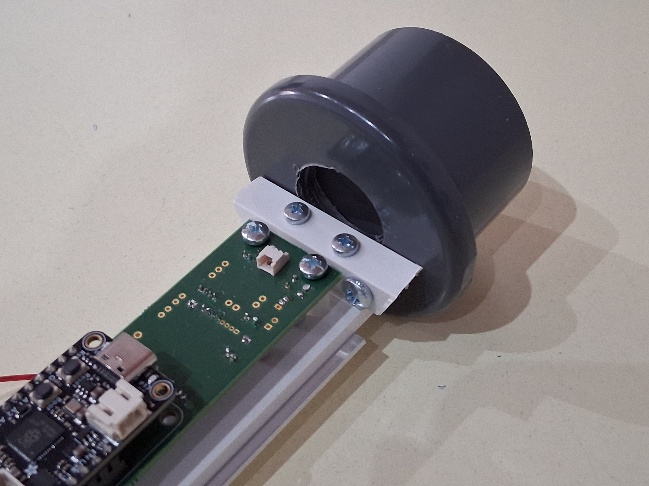
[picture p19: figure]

Figure 9: using PVC and ALU bars mounted on endcap (B)

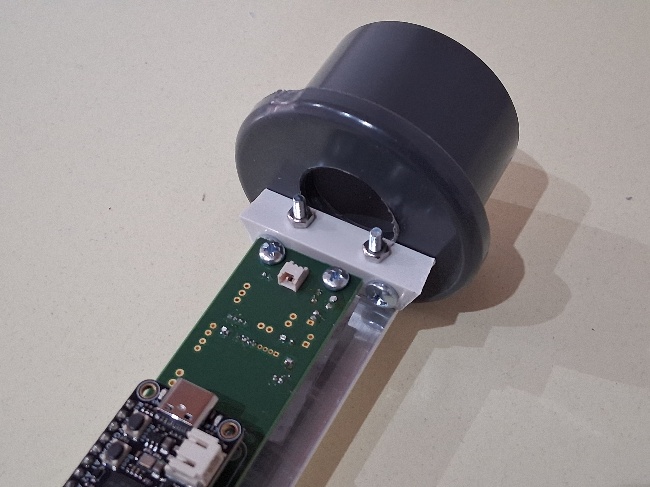
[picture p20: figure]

Figure 10: Using only ALU bar mounted on endcap (B)

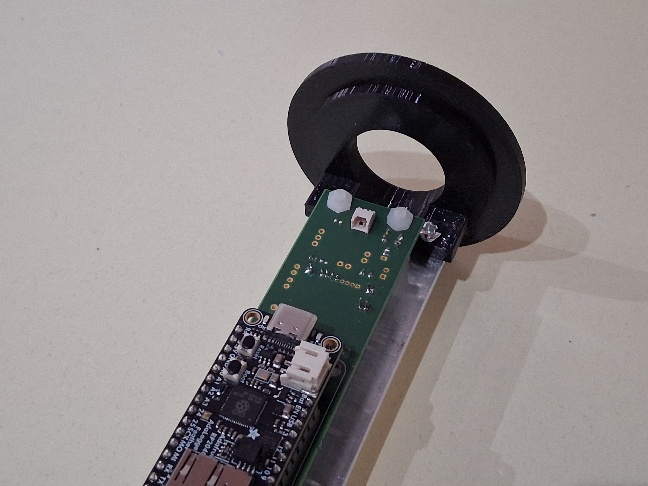
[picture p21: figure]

Figure 11: Using only ALU bar mounted on an 3D printed mounting structure.

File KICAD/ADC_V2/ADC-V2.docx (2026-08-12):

ADC-V2

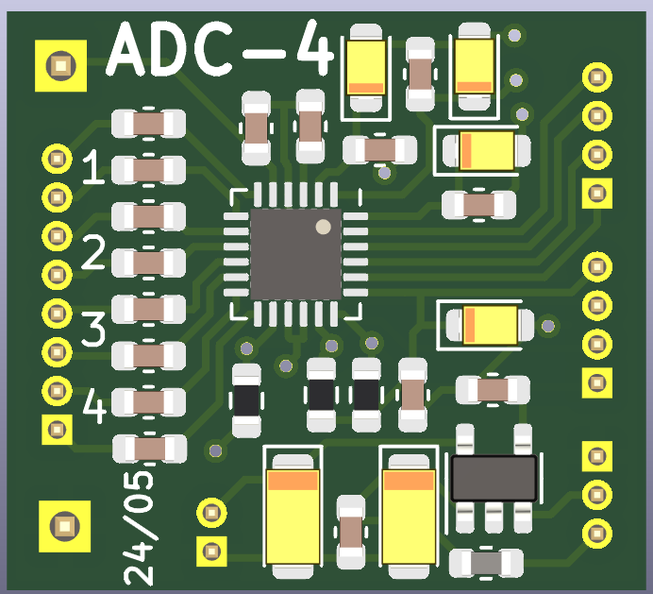
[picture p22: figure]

+

FSYNC
BCLK
SDOUT
GPIO1

IOVD
SHDNZ
SCL
SDA

GND
VIN_EN
VIN

Left side connection to preamps (differential or single ended+ground)
right side connection to MCU (I2S, I2c)

VIN_EN must be digital high to enable LDO,

SHDNZ must be set to high to activate ADC

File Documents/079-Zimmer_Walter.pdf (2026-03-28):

## Hydrophones

SQ17-00

## Sensortech (CA) S = -205 dB//1V/Pa C = 1.6 nF

## Use cases

- Generation of science-grade marine acoustic data for supporting entry-level bioacoustics scientific research (e.g. for undergraduate and graduate students) - Environmental monitoring of coastal marine areas (being protected or not) up to a sensor depth of 100 m - Acoustic recorders for underwater vehicles - Promotion of marine bioacoustics in STEM education

## Concept

- Use commercially available components were possible - PVC pressure tubes for underwater housing - Digital recording components - Hydrophones - Use custom components were necessary - Analog front-end (preamp and ADC) - Hydrophone mounting - Avoid use of expensive machinery - Calibration to allow comparisons and exchanges of data - Restrict use cases to coastal activities or shallow deployments - Minimize power consumption to increase endurance - Open-Source Hard and Software (QR code top-right)

## Objective

- Foster innovation and broadening participation in marine research conservation, and restoration
- Provide a cost-effective, open-source solution for accessing and recording underwater sound.
- Implement a low-cost solution without limitations on sound quality (science-grade data).

# Low-Cost Marine Recorder (LC-MARE) Building your own underwater sound recorder

## Construction options

Walter MX Zimmer
wzimmer@wmxz.eu
Jim Theriault
Ocean Environmental Consulting, Halifax, NS Canada
Lucille Chapuis
La Trobe University, Melbourne, Victoria, Australia

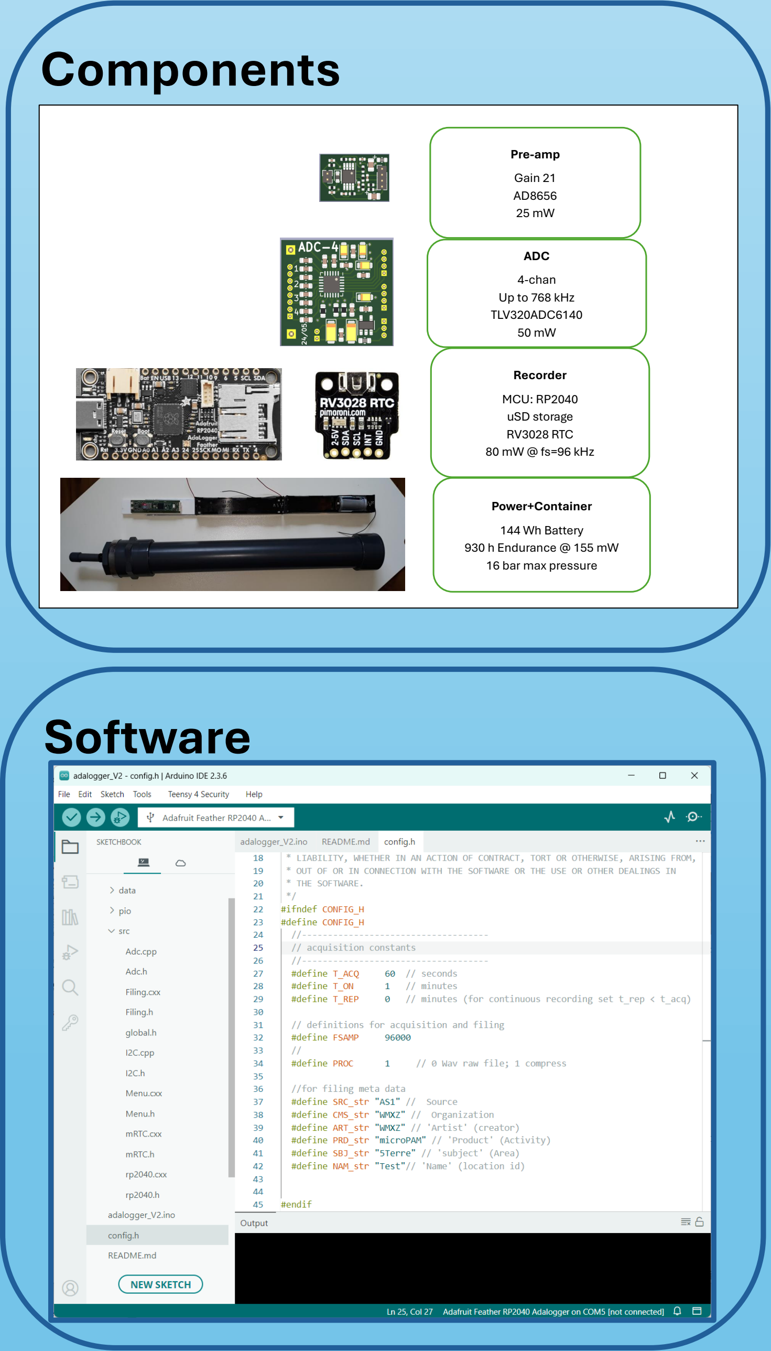
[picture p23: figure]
Software; Components; Pre-amp; Gain 21 AD8656 25 mW; ADC; 4-chan Up to 768 kHz TLV320ADC6140 50 mW; Recorder; MCU: RP2040 uSD storage RV3028 RTC 80 mW @ fs=96 kHz; Power+Container; 144 Wh Battery 930 h Endurance @ 155 mW 16 bar max pressure

## Comments

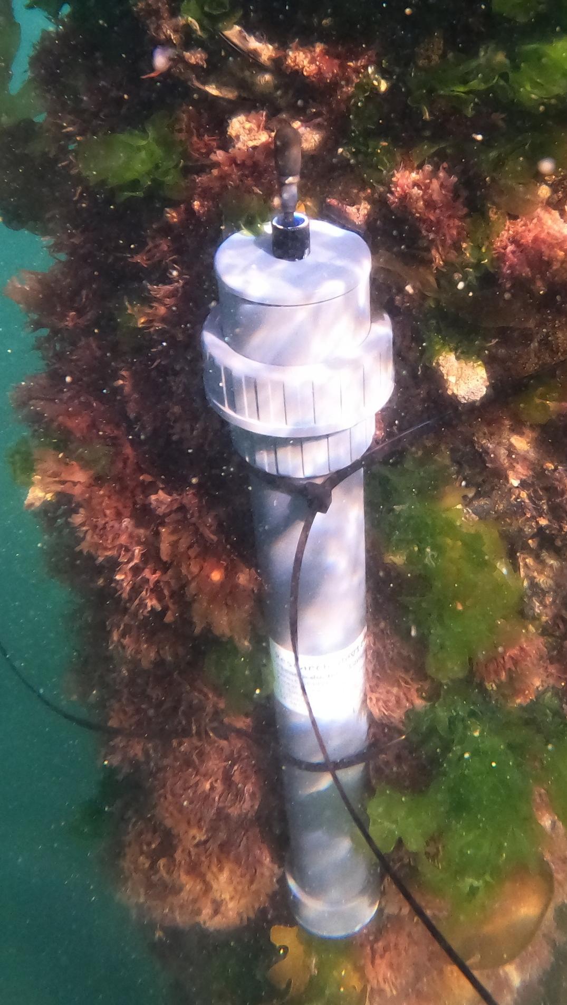
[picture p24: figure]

- Building a science-grade high-performing underwater sound recorder is possible without the use of expensive machining tools.
- Essential for the success is the limitation of use cases to recorder depth of up to about 100 m, suitable for PVC pressure tubes.
- Using a rectangular form factor of the electronics and sequential arrangement of batteries are necessary to limit the diameter of the pressure containers.
- The use of COTS electronic components and modular approaches helps to experiment with custom modifications of the components.
- The use of custom components for pre-amplifiers and Analog-Digital-Converters is affordable if obtained in larger quantities suggesting coordinated efforts.
- Different mounting options of the electronic pack allow flexible adaption to the availability of pressure housing components.
- Use of 3D printer eases mounting of electronics and battery packs
- Software development using the Arduino infrastructure allows easy adaptions of firmware to use-case specific requirements.
- Hydrophones are still the most expensive part of recorder but coordinated procurement efforts can reduce costs.
- Multiple options to assemble hydrophones allow flexible adaption to the availability of components (e.g. pressure container penetrator)
- The actual material cost of LC-MARE is about 320.0 € (Electronics: 110 €; Pressure container: 20 €; Hydrophone SQ17: 190 €)

Nr 079

WMXZ | S1

SQ17-V1

SQ17-V2

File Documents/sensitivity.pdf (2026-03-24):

## Hydrophone Sensitivity

Walter MX Zimmer

22-03-2026

Contents:

- Reference
- Cylinder
– Lamé equations
- Electric field
– Note:
– generated voltage
- Sphere

Reference

https://engineeringlibrary.org/reference/thick-pressure-vessels-air-force-stress-manual

https://apps.dtic.mil/sti/pdfs/AD0759199.pdf

Cylinder

Given a cylider with a,b as internal,external radius stress is given by the Lamé equations.

Lamé equations

For cylinder we have the following stress equations

radial tension
T3(r) = A −

B
r

2

circumferential tension
T1(r) = A +

B
r

2

1

axial tension (end-capped cylinder)

T2(r) = A

whereby

A =

Paa

2 − Pbb

2
b

2 − a

2

B =

a

2
b

2
(Pa − Pb)
b

2 − a

2

Assume for hydrophones internal pressure Pa = 0, then the two constants A and B become
A = −Pb

b

2
b

2 − a

2

B = −Pb

a

2
b

2
b

2 − a

2

= Aa²

and the three stress equations are then

T3(r) = A(1 −

a

2
r

2

)

T1(r) = A(1 + a

2
r

2

)

T2(r) = A

with A as defined above

Electric field

The electric field in radial direction E3(r) due to external pressure becomes with

g32 = g31
E3(r) = −g31(T1(r) + T2(r)) − g33T3(r)

and the measured voltage V

V =

Z b

a

E3(r)dr

Note:
Z b

a

dr = b − a
Z b

a

1
r

2

dr = −(

1
b

−

1
a

) = b − a
ab
that is
Z b

a

(1 ±

a

2
r

2

)dr = (b − a) ±

a(b − a)
b

= (b − a)(1 ±

a
b

)

2

Generated voltage

V = −

Z b

a

(g31(T1(r) + T2(r)) + g33T3(r))dr

V = −A(b − a)

g31(2 + a
b

) + g33(1 −

a
b

)

V = −Pbb

b
b + a

g31(2 + a
b

) + g33(1 −

a
b

)

Let t =

a
b

then

V = −Pbb

1
1 + t
g31(2 + t) + g33(1 − t)

Sphere

T3(r) = Pb

b

3
a

3 − b

3

(1 −

a

3
r

3

)

T1(r) = T2(r) = Pb

b

3
a

3 − b

3

(1 + a

3
2r

3

)

With
Z b

a

1
r

3

dr = −

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
) = 1
2

b

2 − a

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
b + a

ab )( b − a
ab )

and therefore
Z b

a

(1−

a

3
r

3

)dr = (b−a)−

a

3
2

b + a
ab

b − a
ab = (b−a)(1−

a
2b

b + a
b

) = (b − a)
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
(1+1
2

a

3
r

3

)dr = (b−a)+1
2

a

3
2

b + a
ab

b − a
ab = (b−a)(1+1
2

a
2b

b + a
b

) = (b − a)
4

(4+a
b

+

a

2
b

2

)

one gets

V = −Pb

b

3
b

3 − a

3

(b − a)
2

g31(4 + a
b

+

a

2
b

2

) + g33(2 −

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
and finally

V = −Pb

b
2

b

2
b

2 + ab + a

2

g31(4 + a
b

+

a

2
b

2

) + g33(2 −

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
which again is equivalent to

V = −Pb

b
2

1
1 + t + t

2

g31(4 + t + t

2
) + g33(2 − t − t

2
)

3

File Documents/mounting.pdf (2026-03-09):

# Alternative mounting

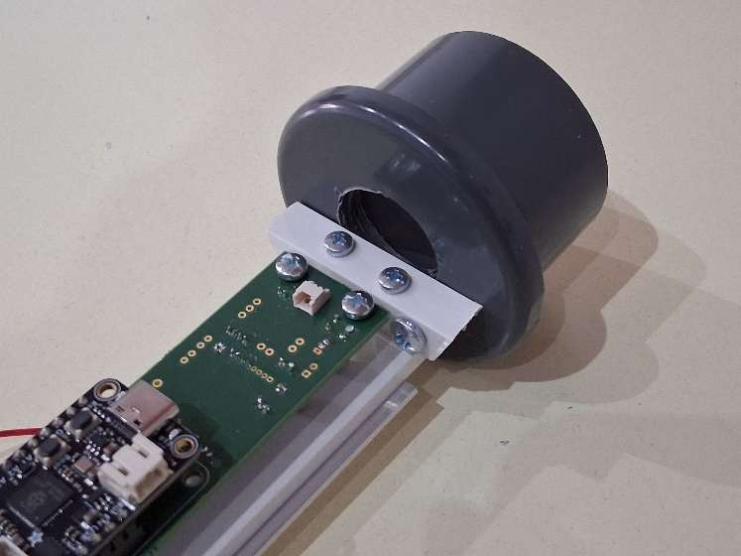
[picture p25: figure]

Figure 5: using PVC and ALU bars mounted on endcap (B)


Figure 6: Using only ALU bar mounted on endcap (B)


Figure 7: Using only ALU bar mounted of 3D printed mounting structure

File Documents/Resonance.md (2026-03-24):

# Bubble resonance under pressure

## Boyle's equation
$$
P(z)V(z)=P_0V_0=const
$$

## Bubble volume
$$
V(z)=\frac{4}{3}\pi a^3
$$
$$
V(z)=V_0\frac{P_0}{P(z)}=\frac{V_0}{(1+0.1z)}
$$
$$
a(z)=\frac{a_0}{(1+0.1z)^{1/3}}
$$

## Minnaert resonance
$$
f=\frac{1}{2\pi a}\big(\frac{3\gamma P_A}{\rho}\big)^{1/2}
$$
$$
f(z)=\frac{1}{2\pi a}\big(\frac{3\gamma P_0}{\rho}\big)^{1/2}(1+0.1z)^{1/2}
$$
$P_0$ = 100 kPa
$\rho$ = 1000 $kg/m^3$
$\gamma$ = 1.4
$$
f(z)\times a=3.26 (1+0.1z)^{1/2} \ m/s
$$

## Clay and Medwin (from Cato)
$$
f=3.25\frac{(1+0.1z)^{1/2}}{a}
$$

## Test
$$
f=3.26\frac{(1+0.1z)^{1/2}}{a_0}(1+0.1z)^{1/3}
$$
$$
f=3.26\frac{(1+0.1z)^{5/6}}{a_0}
$$

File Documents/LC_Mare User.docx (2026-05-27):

# LC_Mare

## Generate config.txt

The file config.txt is used to keep essential parameters during hibernation. It may also be used to generate a delayed start, to modify some meta data well before deployment. The file resides in the microSD card. If not present the software will use default values for all parameters that are hard coded during compilation.

The easiest way to generate a proper formatted config.txt file is to insert a blank disk into the recorder, disconnect the batteries and connect to PC via USB. The program will start up and start recording. On connected Terminal program stop program execution by pressing “e”. By pressing “y1”+return, the program will generate a config.txt file and hibernates until the next full minute. Once the program has restarted, it can be stopped again with pressing “e”. The generated config.txt file can now be edited.

Example config.txt file

# configuration file

# should end with '#' or ';' comment may follow

!a 60 # file size (sec)

!o 2 # on time (min)

!r 0 # repetition interval (min)

!f 384 # sampling frequency (kHz)

!g 20 # analog gain (dB)

!s AS1 # (ISRC) source with sensitivity

!c WMXZ # (ICMS) commissioning organization

!n WMXZ # (IART) name of operator (creator)

!p microPAM # (IPRD) project

!e 5Terre # (ISBJ) area

!l Test # (INAM) location id

!1 0 # h_rec[0]

!2 12 # h_rec[1]

!3 12 # h_rec[2]

!4 24 # h_rec[3]

!x 2026-05-23_00:00:00 # start time yyyy-mm-dd_hh:mm:ss

### Comments:

All commands start with exclamation mark followed by a single alpha-numeric character and content of the command.

Specific comments:

- while file size is given in seconds (here 60), on-time and repetition interval are given in minutes, and h_rec values are given in hours.
- The sampling frequency is given in kHz.
- Wav meta data (e.g. ISRC) are alphanumeric values up to 40 characters
- The start time (‘!x’) must follow the presented format and especially date and time must be separated by an underscore ‘_’.

### Run timings:

Run timings are controlled by the commands ‘!x’,’!a’,’!o’,’!r’,’!1’, … ‘!4’.

- ‘!x’ denotes the start time of the acquisition. If in the past, program will start immediately
- ‘!a’ is the nominal length of each file. The algorithm works in such a way that all files are closed once the indicated time has exceeded. So, for ‘!a 60’ the file is closed at the end of the minute and for ‘!a 20’ the file is closed at (20s, 40s, 60s)
- ‘!o’ is the on-time of each acquisition period and works in combination with the repetition interval. The time is given in minutes and is always greater then zero
- ‘!r’ defines the duty cycle of intermittent recordings if its value is greater than the on time. If set to zero, it has no effect and acquisition is continuous. An example for duty cycle recording could be ‘!o 5’ and ‘!r 15’ , which results in 5 minutes acquisition every 15 minutes. As with the file size the repetition rate generates ‘nice’ file times. So, for the 15 minute repetition the off time will end at 15min, 30min, 45min and 60 min.
- The h_rec parameters can be used to limit the acquisition to one or two periods per day. Acquisition will occur between h_rec[0] and h_rec[1] and between h_rec[3] and h_rec[4]. To ensure continuous recording h_rec[0] must be set to 0, h_rec[3] be equal to h_rec[2],and h_rec[4] must be set to 24. The default values are for continuous recording.

## LC-Mare-GUI

The python script LC-Mare-GUI.py may be used to interface with the recorder and to easily edit some basic parameters and to synchronize the real-time-clock (RTC).


Buttons:

Load: to update fields from device

Sync: to synchronize MCU RTC to PC clock

Save: to write fields back to device. Needed after modifications made on GUI.

Reboot: triggers a reboot of device. Start Time will be considered if at later time.

Exit: exits program

Start: start the acquisition, will become stop button. Messages from device will be shown in window. Use of GUI will initialize start Time to GUI launch time.

## Analysis programs

LC Mare files can either be compressed (.bin) or plain wav files (.wav). Some scripts are also presented as .ipynb (jupyter notebook) files.

### LC_Mare-Bin2Wav.py

Converts compressed (.bin) files to standard .wav files

### LC_Mare-Info.py

Presents key parameters from LC Mare files

### LC_Mare-Listen.py

Allows to listen to LC-Mare files (audio will be amplified to 1/10-th of full scale)

### LC_Mare-Vew.py

Simple spectrogram viewer of single LC Mare files

### microPAM-Viewer.py

Better viewer of with different processing options for microPAM (i.e. LC Mare) files

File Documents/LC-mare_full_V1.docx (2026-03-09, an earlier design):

# LC-MARE

Walter MX Zimmer

27-07-2024

## Objective

Aim of the low-cost marine autonomous acoustic recorder (LC-MARE) is to provide a cost-effective solution to access and record underwater sound. The implementation should be low-cost but without limitations on sound quality.

## Use cases

The envisioned use cases are defining the required characteristics of the LC-MARE autonomous recorder, and it is envisioned that LC-MARE,

- generates marine acoustic data that support
  - entry-level scientific research (e.g. for undergraduate and graduate students)
  - environmental monitoring of coastal marine areas (being protected or not)
  - marine bioacoustics in STEM education
- is used up to a water depth of
  - 100 m, if connected to surface buoy
  - 40 m, if placed on bottom by recreational scuba diver
- Is recording acoustic data with or without duty cycling
- may be calibrated to allow comparisons and exchanges of data

## Concept

The implementation should be low-cost but without constraints on quality.

There are different levels of complexity and cost factors.

- Commercially available components:
- Piezo ceramic tubes
- Programmable recording system (MCU, microSD card, RTC)
- Pressure housing components

These components are typically produced in quantities and no major cost saving is anticipated.

- Specific made components:
- Analog amplifier
- Analog-digital conversion
- Base board (to avoid cabling)

These components are specific made for LC-MARE and the ‘set-up’ costs are usually higher than the component costs. Therefore, only the production of multiple units (say 100+units) reduces the price-tag per unit to nearly the component costs.

- Custom made components:
- Hydrophone construction
- Pressure vessel construction
- Mounting frame

Depending on the use cases and individual skills these components may be build by the interested users, whereby the hydrophone construction is the most demanding task and may be appropriate only for experienced users. It is expected that, while DIY is possible, for most users the hydrophones are constructed by specialized businesses.

The construction of pressure vessels depends again on the use-cases and assuming shallow water applications (recorder depth <100 m) user build pressure vessels are feasible using pressure-rated PVC tubes and fittings.

## Implementation


### Hardware

Figure 1_ Components of LC-MARE prototype

Power+Container

135 Wh Battery

200 h Endurance

16 bar max pressure

Pre-amp

Gain 21

AD8656

ADC

4-chan

TLV320ADC6140

Recorder

MCU: Teensy 4.1

uSD storage

USB PC-I/O

Electronics

Dual pre-amp

ADC

Recorder

DC/DC converter

DC/DC

5V

Line filter

The components of a first LC-MARE prototype are shown in Figure 1. The electronics is composed of multiple components to facilitate easy replacement of components, if deemed necessary.

Length and diameter of the pressure tube are determined by the size of the battery holders and resulted to 500 x 63 mm for a 6 D-Cell battery pack. Using additional fittings and tubes, the power supply can easily be extended by adding additional four battery containers.

The pressure tube and fittings are 16 Bar rated PVC tubes, commercially made for water pipe constructions, e.g. for swimming pools.

### Software

The software is using standard C/C++ code and by being compatible with the Arduino infrastructure it is easily maintained, modified and downloaded to the microcontroller of the LC-MARE. The few parameters that are expected to be modified at sea are provided by a file on the microSD card that can be prepared prior to the at-sea activity.


Figure 2: LC-Mare August 2024 version

## Implementation details

The LC-MARE implementation will be open source and hard and software implementation will be published at GitHub - WMXZ-EU/LC-MARE: low-cost marine acoustic recorder (https://github.com/WMXZ-EU/LC-MARE)

### Hydrophone


Hydrophone consists of three components: Cylindrical piezo-ceramic tube, BlueRobotics penetrator, and polyurethane rubber. The hydrophone is at some distance from the penetrator to reduce acoustic interference of the pressure container. The use of BlueRobotics penetrators facilitates the changes of hydrophones and pressure containers.

### Pressure Container


1.25 €

500 mm: 3.00 €

2.67 €

2.20 €

PVC-U: PN16 tube, diameter 63 mm: Euro

LC-MARE pressure container

The pressure container consists of 4 components a 500 mm long tube, an endcap, an adapter with internal thread and a plug with external thread and O-ring. To connect the hydrophone a 10 mm hole will be drilled in the plug. The PVC-U components are rated with PN16 and should withstand 16 Bar internal pressure. It is expected that they also withstand 16 Bar external pressure, which corresponds to a water depth 150 m. The PVC-U tubes and fittings are purchased from an online store (pcv-welt.de) but may be found in hardware stores.

### Mounting system

The electronic and battery packs are mounted onto an aluminium plate (35x50x2) by means of double-sided adhesive tapes. To separate electronics from conducting aluminium an additional PVC plate is added. The mounting plate is attached to hydrophone penetrator using an aluminium U frame. All components are from the local hardware store.

### Electronics

For the electronics we have following components

#### Pre-amplifier

The pre-amplifier is a differential-to-differential voltage amplifier, the Spice simulation is shown next:


Gain is controlled effectively by the resistor R1. There is still some gain increase at 400 kHz, that can be removed by increasing the feedback capacitors C3, C7 somewhat. The selected OP-AMPS are of CMOS type with 2.7 nV/sqrt(Hz) noise voltage each.


A more lower noise pre-amplifier with FET and ultra-low noise bipolar amplifier would be a possible alternative and is in development.

#### Analog Digital Conversion

The ADC is based on the Texas Instruments TLV320ADC6140 chip and implements the circuitry of the datasheet.

The ADC features 4 differential input channels each of which can be amplified up to 40 dB. A dedicated LDO regulator provides 3.3V for the analog circuitry.

Sampling frequencies can be up to 768 kHz for a single channel, 384 kHz for two channels and 192 kHz for all four channels. Bit depth is 24 bit.


#### Putting it all together


The final electronics board features 1 or 2 pre-amps, a 4-channel ADC, a Teensy 4.1 MCU, a TRACO DC-DC convertor with power-supply filtering and a magnetic proximity switch. An external Coin cell provides a backup battery for the MCU-based Real-Time-Clock.

## Software

Fully programmed with C/C++ code but can be compiled and downloaded within the Arduino ecosystem or using Makefiles.

All software is available on GitHub.

Data storage is using ExFat filesystem and after moving the disk, the data can be accessed directly by the PC. This allows also to store/edit configuration files on the disk ahead of closing the pressure container.

TODO: finalize the exact protocol to start deployment (e.g. start recording at a specified day and hour)

Multi-level duty-cycling may be implemented as shown following

Level 1: for deployment

d_on: number of days on (in days)

d_rep: number of days for start of recording block (d_rep >= d_on, otherwise every day)

Level 2: for each day of acquisition:

h_1: on-hours first period

h_2: off hour first period

h_3: on hour second period

h_4: off hour second period

Level 3: for each acquisition period

t_on: recording on in s

t_rep: recording period in s (0 is continuous. 600 means every 10 min)

In case an external connector is implemented that provides USB access to the MCU, data can be retrieved via MTP protocol and parameters may be retrieved and stored via USB serial protocol. To minimize the cost, the LC-MARE does not feature an additional connector.

### GUI

The following Python based GUI shows some of the parameters that may be retrieved and stored and may be the basis for a Custom GUI.


This GUI shows some parameters that are used for controlling the functionality of LC-MARE

The Form will be populated with the ‘Load’ button. The ‘Sync’ button will synchronize the RTC with the PC time. Parameters will be downloaded to MCU using the ‘Save’ button. The ‘Store’ button saves the parameters to MCU and stores them on microSD disk and EEPROM. This is of importance for duty-cycling, where MCU will be switched off.

Parameters shown in GUI:

- fsamp: sampling frequency in Hz
- proc: online processing: 0 wav file; 1: integer loss-less compression
- shift: in case of compression indicates the number of lower bits that are to be ignored
- again: analog gain in dB in ADC
- t_acq: length of files in s
- t_on: length of acquisition block in s
- t_rep: time in s between starts of acquisition blocks in s (0 means continuously)
- h_1: start hour of first acquisition period
- h_2: end of first acquisition period
- h_3: start of second acquisition period
- h_4: end of second acquisition period
- d_on: length of recording block in days
- d_rep: time in days between starts of recording blocks in s (0 means every day)

In above GUI image, the acquisition timing parameters are set for continuous recording

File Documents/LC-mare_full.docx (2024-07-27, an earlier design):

# LC-MARE

Walter MX Zimmer

27-07-2024

## Objective

Aim of the low-cost marine autonomous acoustic recorder (LC-MARE) is to provide a cost-effective solution to access and record underwater sound. The implementation should be low-cost but without limitations on sound quality.

## Use cases

The envisioned use cases are defining the required characteristics of the LC-MARE autonomous recorder, and it is envisioned that LC-MARE,

- generates marine acoustic data that support
  - entry-level scientific research (e.g. for undergraduate and graduate students)
  - environmental monitoring of coastal marine areas (being protected or not)
  - marine bioacoustics in STEM education
- is used up to a water depth of
  - 100 m, if connected to surface buoy
  - 40 m, if placed on bottom by recreational scuba diver
- Is recording acoustic data with or without duty cycling
- may be calibrated to allow comparisons and exchanges of data

## Concept

The implementation should be low-cost but without constraints on quality.

There are different levels of complexity and cost factors.

- Commercially available components:
- Piezo ceramic tubes
- Programmable recording system (MCU, microSD card, RTC)
- Pressure housing components

These components are typically produced in quantities and no major cost saving is anticipated.

- Specific made components:
- Analog amplifier
- Analog-digital conversion
- Base board (to avoid cabling)
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

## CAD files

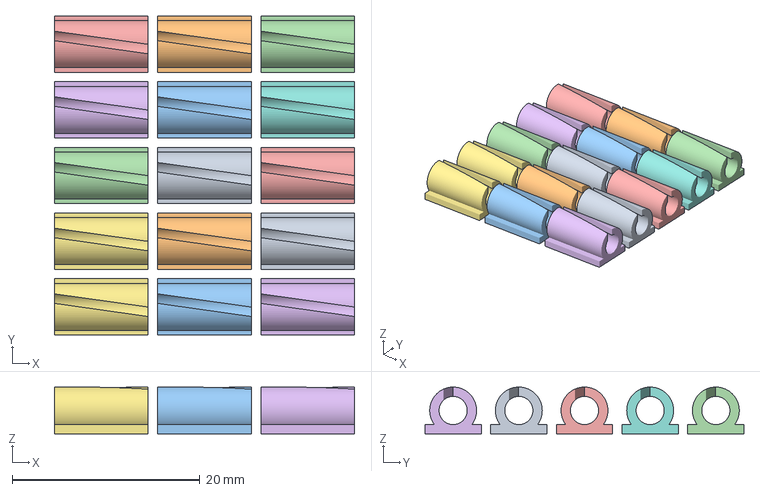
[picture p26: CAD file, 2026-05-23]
3D-models/wire-hold.3mf
32.0 x 34.0 x 5.00 mm
wire-hold.stl x 15

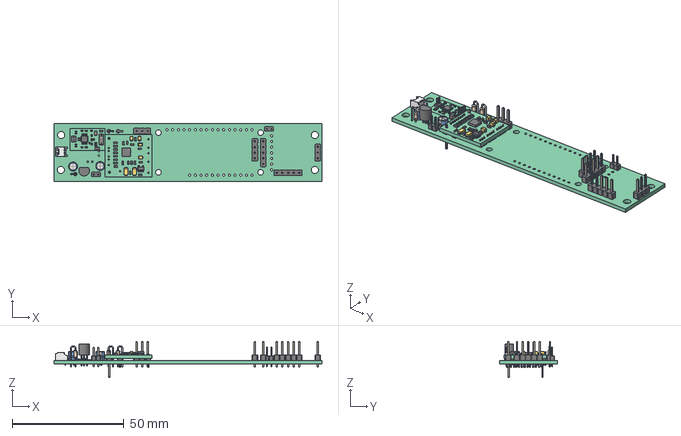
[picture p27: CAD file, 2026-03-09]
KICAD/LC_PAMV4b1/LC_PAMV4b1.step
120.0 x 26.0 x 16.2 mm
Board_Geoms_97
Top_97 x 16

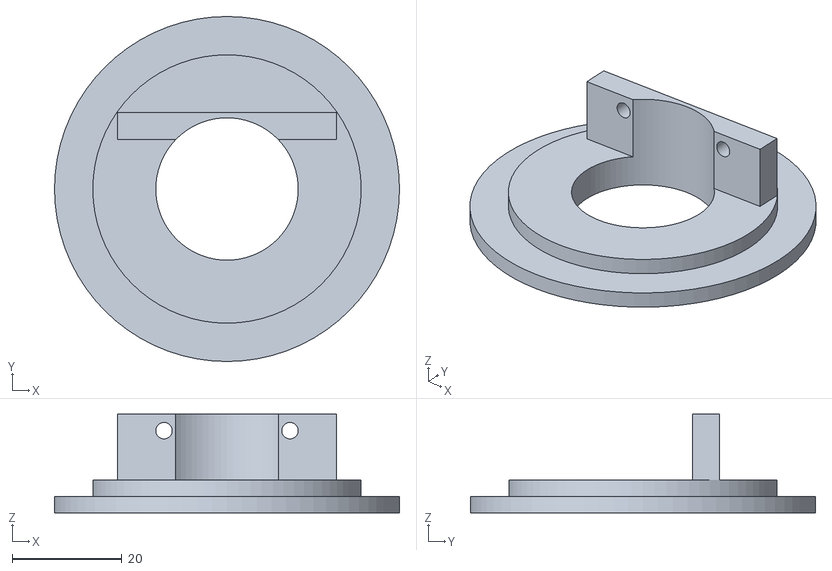
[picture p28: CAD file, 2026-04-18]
3D-models/mounting.stl
63.0 x 63.0 x 18.0

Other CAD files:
3D-models/wire-hold.stl
KICAD/LC_PAMV4b1/LC_PAMV4b1.FCStd

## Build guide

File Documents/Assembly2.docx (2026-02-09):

# Recorder electronics

Electronic details

If wanted solder pin-headers to preamp and ADC boards

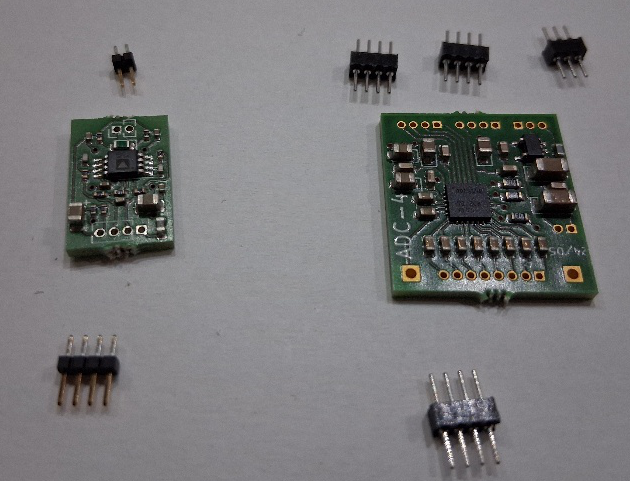
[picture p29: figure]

Using the base board to keep pin-headers straight, but without soldering to base board.

First, preamp

Then ADC board

As we only have connections for the first two audio channels, a 4-pin header is sufficient. The preamp uses pins 3,4, while the preamp of Mark (not shown here) would use, pins 1 and 2.

Connect the pins with some wire or solder as shown in next figure

Solder hydrophone header (here pico plade). To have free room for manoeuvres. Header is soldered on be back side as shown in figure.

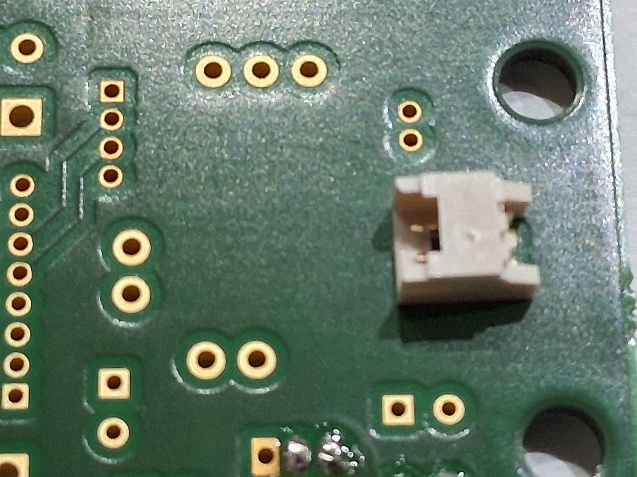
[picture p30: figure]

Solder preamp to base board

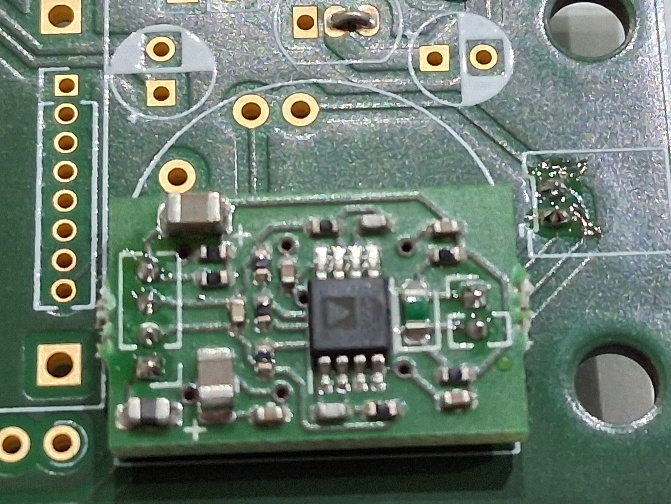
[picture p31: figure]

Solder ADC to base board (only four pins to the right are needed)

Solder 4 wires to additional connect ADC to base board

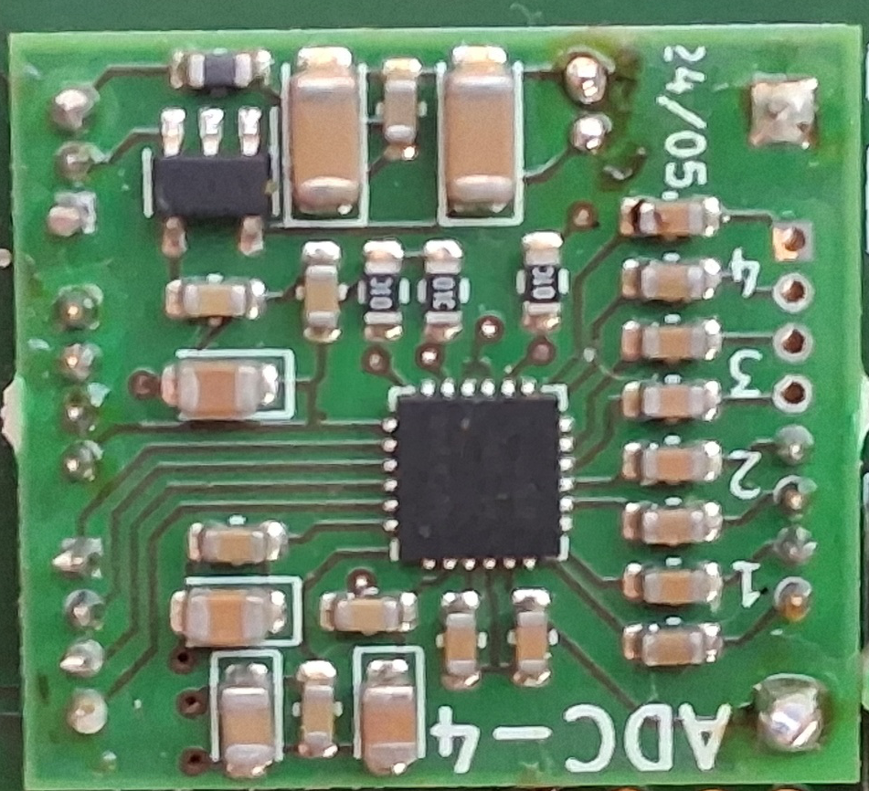
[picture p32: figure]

Solder pin header to Adalogger using short headers (short pin and receptacles)

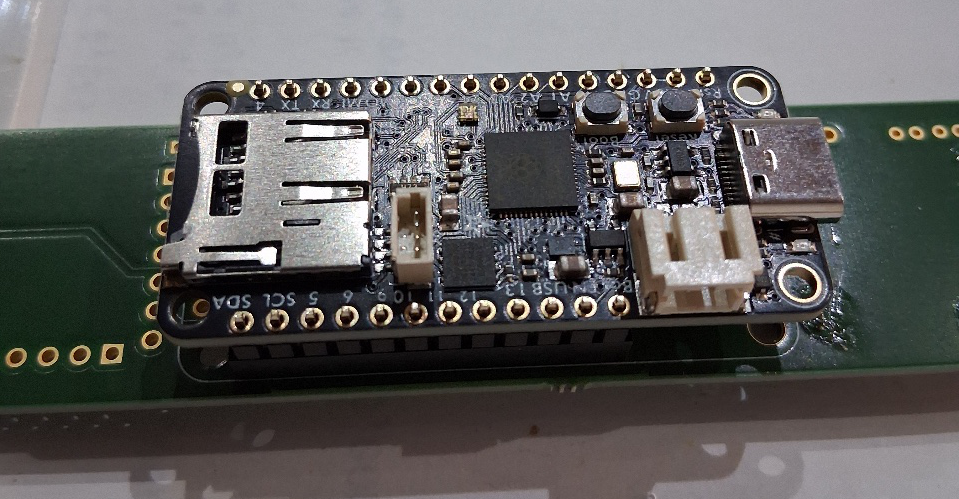
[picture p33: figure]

Solder female header from other side to board (having Adalogger still attached)

Remove Adalogger (for stability) and solder RTC to pin header. Mabe using the provided receptacle to keep board at 90° . Flip base board and solder pins to board.

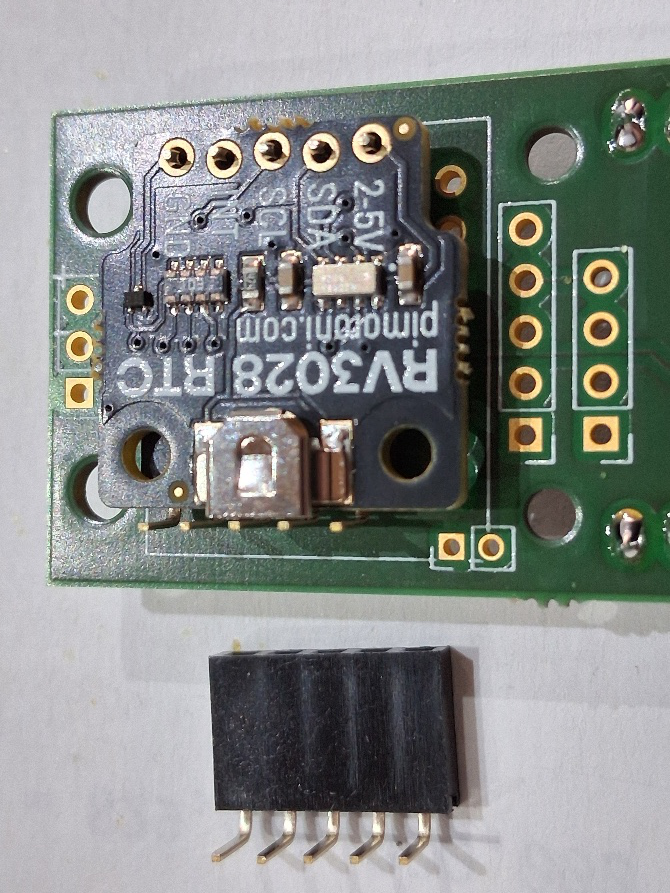
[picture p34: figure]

If needed: solder DC/DC converter with similar procedure as RTC clock (not shown in figure.

If needed: solder ELCOs

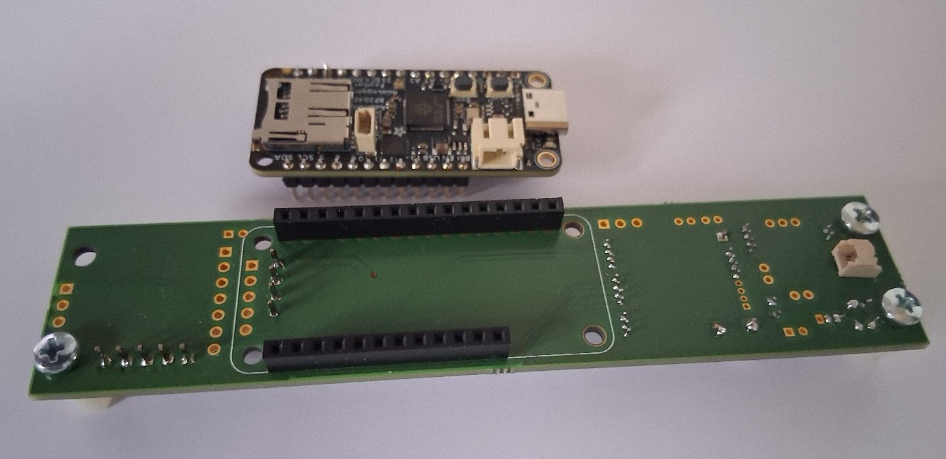
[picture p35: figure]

Close-up of Pre-amp ADC

# Pressure Container

Following instructions are for this configuration:

Endcap A

ID 63 mm

Tube 500 mm

OD 63 mm

Endcap C

OD 50 mm

Endcap B

ID 50 mm

OD 63 mm

Union

ID 63 mm

# Endcaps

Take 63 mm OD flat endcap B, drill 3 mm hole in center

Take endcap (endcap C) with 63 mm top and 50 mm tube, drill 3mm holes also at center

# Mounting bar

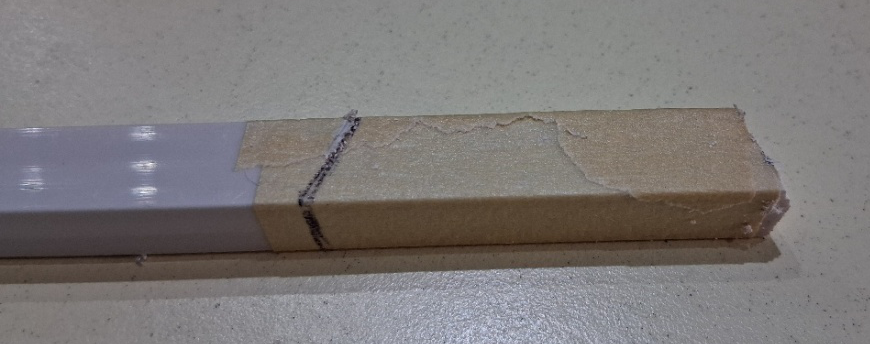
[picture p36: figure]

Cut piece from 10 x 10 mm bar

D

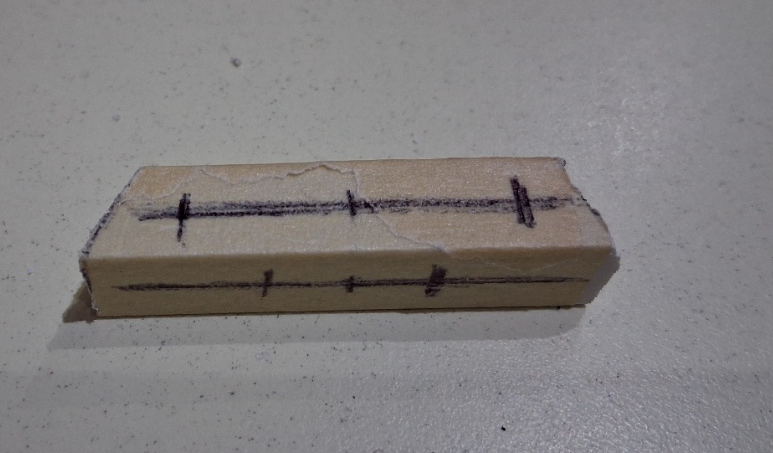
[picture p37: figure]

Mark holes to drill (wider correspond to spacings of drawing used for center holes.

The narower holes are seperated by half the seperation of the wider holes

# Combine mounting bar with Endcap combi

Insert into endcap combi

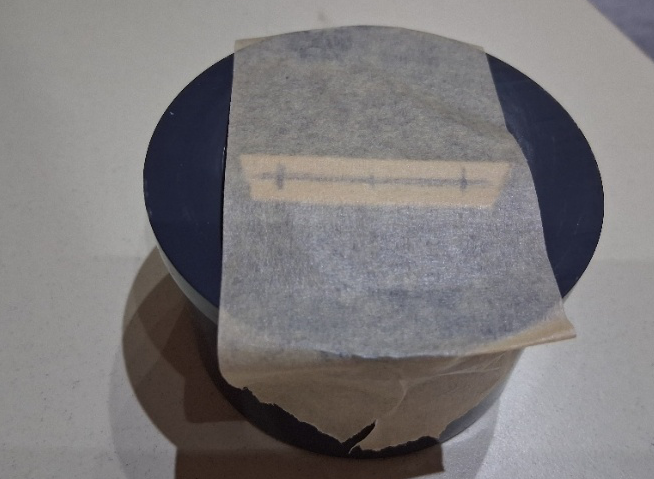
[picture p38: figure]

Fix with tape

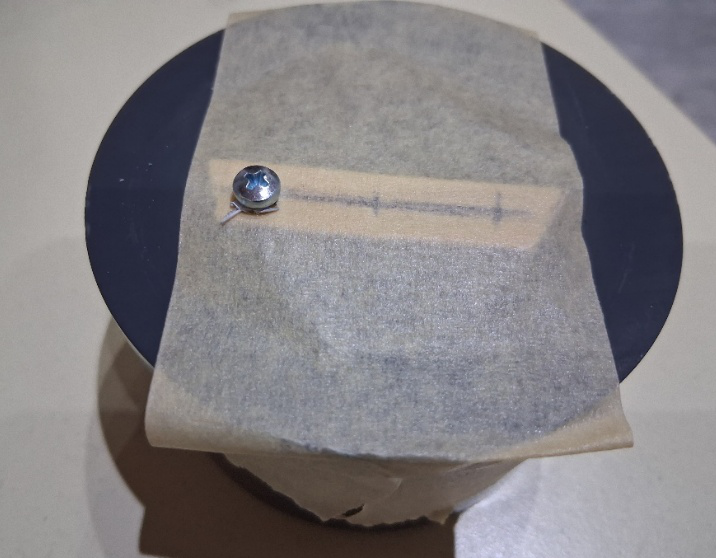
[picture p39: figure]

Drill one 3 mm hole through bar and Endcap C and fix with screw before drilling the other hole

Widen holes in bar to 4 / 4.5 mm

Resulting endcups and holes

# Adjust endcap combi for hydrophone and mounting bar

Widen the hole in the 63 mm OD endcap to 9 mm using tool to be perfectly vertical

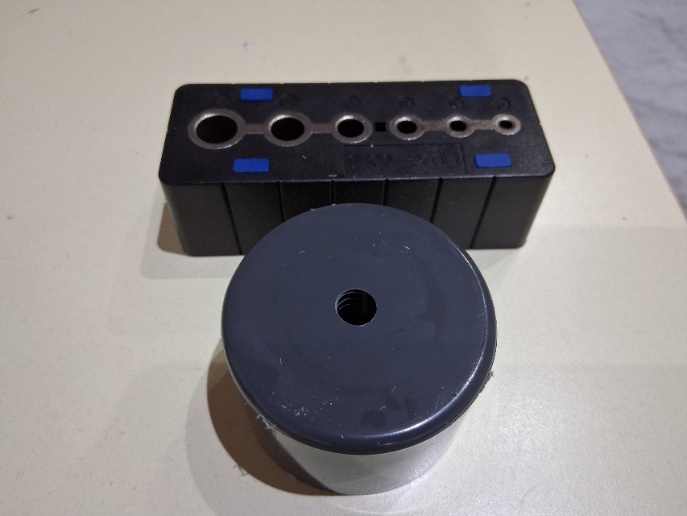
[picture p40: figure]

Cut 10 mm thread into hole of 63 mm endcap

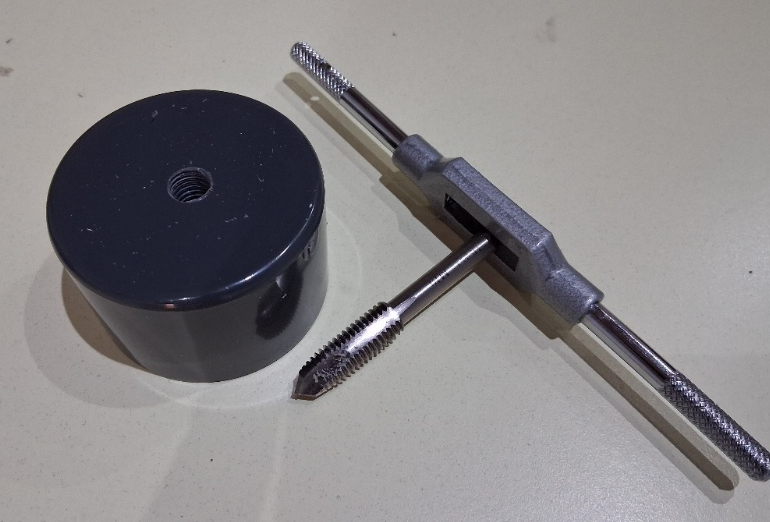
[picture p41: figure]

Cut 4-mm thread in tho off-center holes in 50 mm OD Endcap

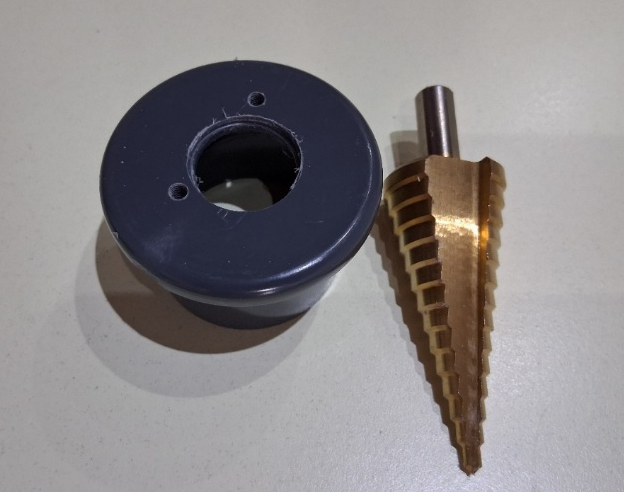
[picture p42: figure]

Widen center hole in 50 mm OD endcap to about 24 mm diameter

# Combine electronics to flat pvc and alu bar

Tape board or stencil om pvc bar and alu bar

Drill 4 holes through pvc and alu plate

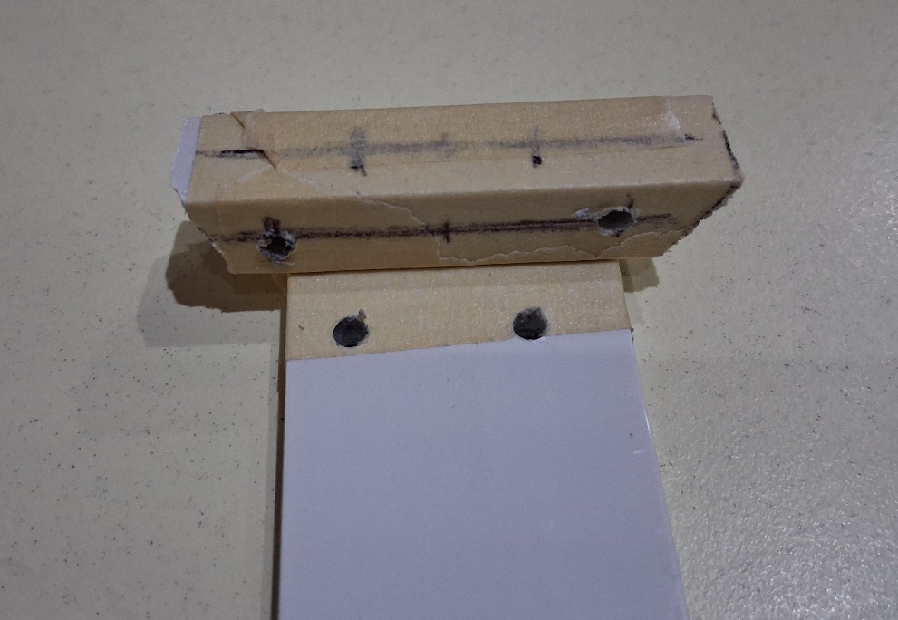
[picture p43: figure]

place 10x10 mm bar on flat PVC bar, smaller side touching plate

drill two 3 mm holes through bar and plate, fix again with 3mm bolt after first hole

Fix pvc plate to alu plate with 12 mm srews and three 10 mm nylon standoff an one nut

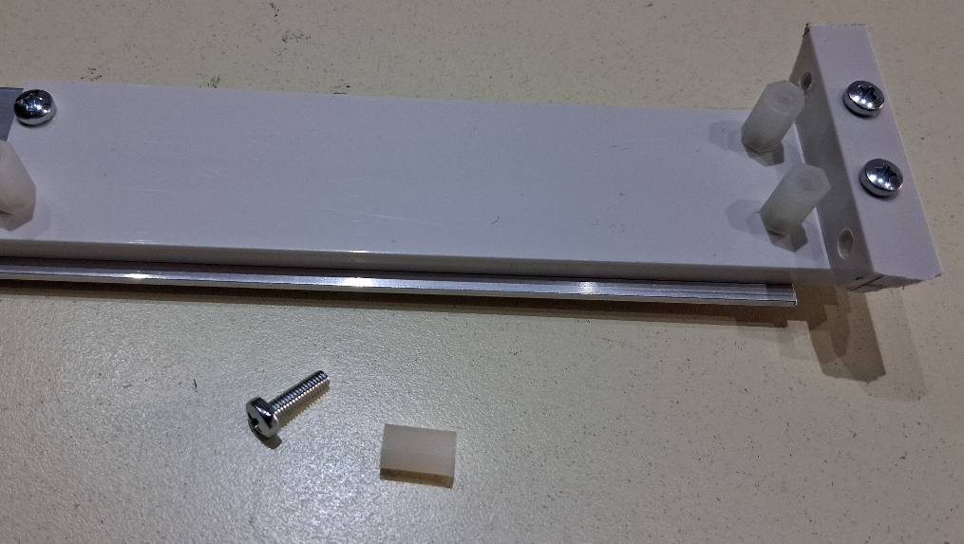
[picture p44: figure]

# Assemble recorder

Press mounting cap (counter end-cap) into hydrophone end-cap

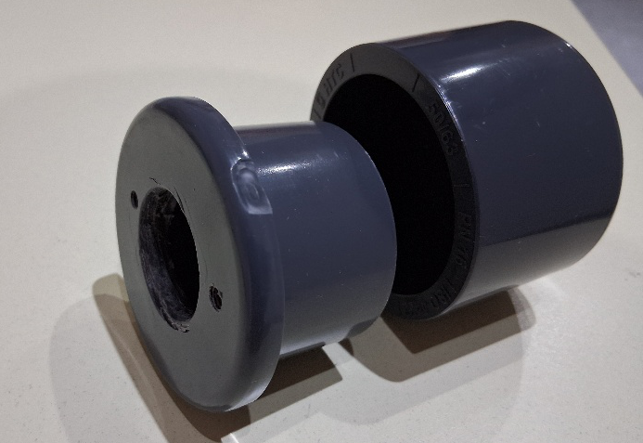
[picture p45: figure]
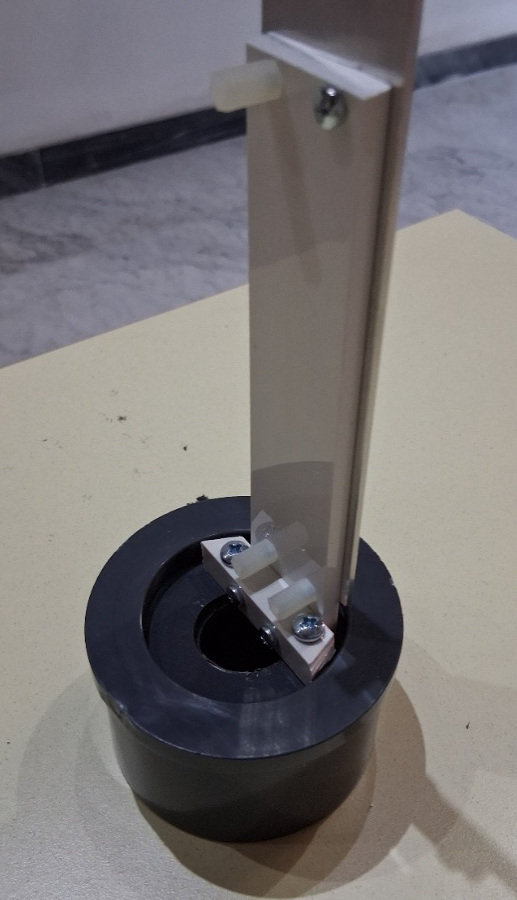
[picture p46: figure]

Assemble mounting plate to endcap combi

Adding recorder

Place battery packs long side alu plate, place 4 double sided tapes on alu plate and fix battery packs, keeping 1 mm distance from pvc plate. Hydrophone holders may extend over 50 cm alu bar.

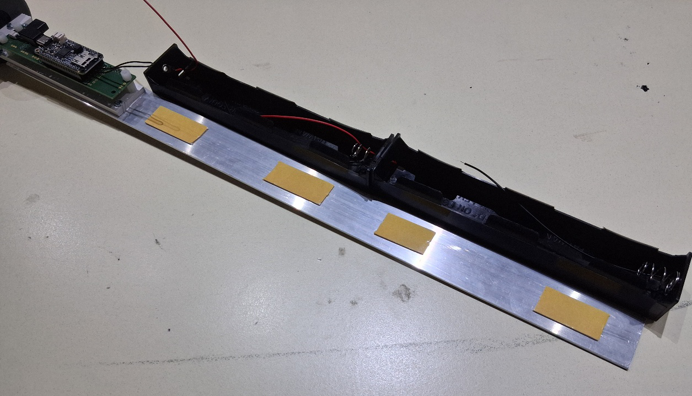
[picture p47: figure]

# Alternative mounting methods

Au U with 10 mm hex nut attached directly to hydrophone penetrator (here with Teensy 4.1) See below.

PVC bar screwed onto counter end-cap

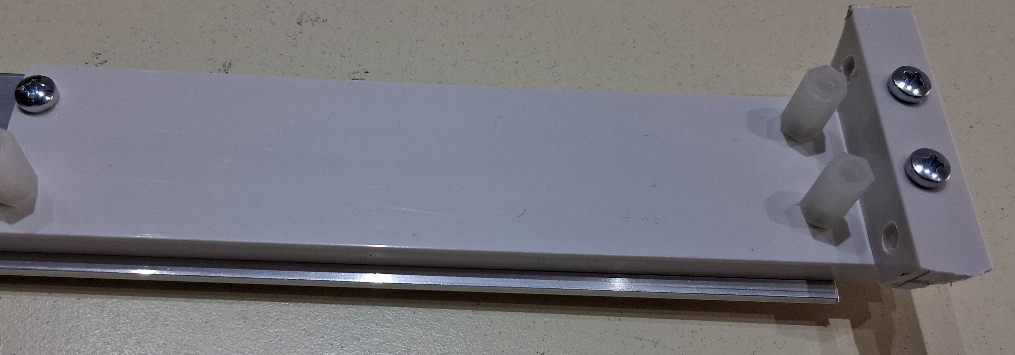
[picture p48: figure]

3D printed insert replacing counter end-cap

# Construction of Alu bracket

Take an Alu U profile (20 x 10 mm)

mark a point in the middle and about 16-17 mm from the end.

Drill a 3 mm hole as precisely as possible at this point

Drill next a 10 mm hole using for example a drill head as shown in picture

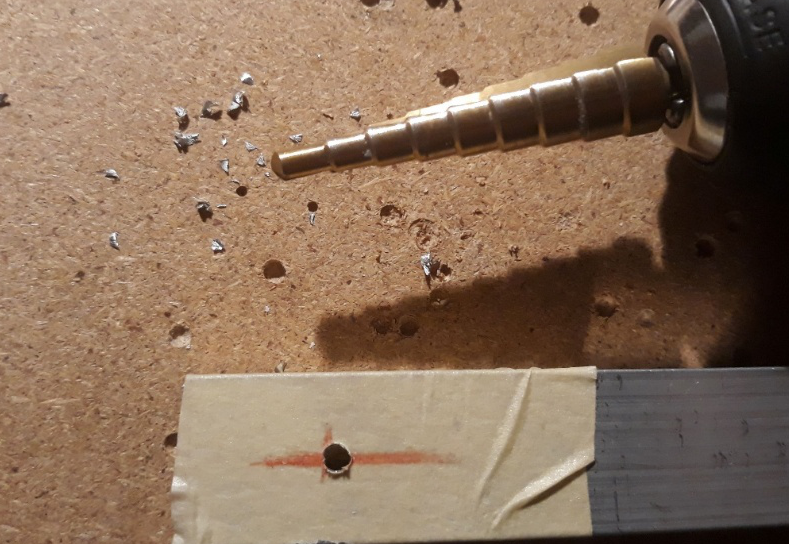
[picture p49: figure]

Cut the Alu U profile such that the 10 mm hole is in the middle.

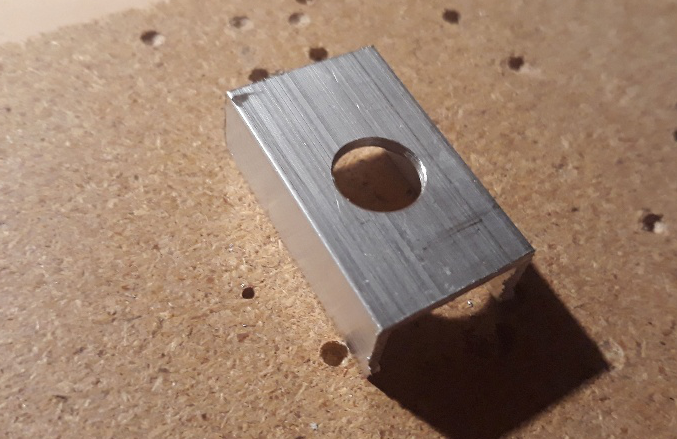
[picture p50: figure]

Fix the Alu U profile on top of the plastic bar (were the electronics will be placed)

Drill from below two 3 mm holes that are about 5 to 6 mm from the end and 4 mm from the side-

Fix the Alu profile to the plastic bar with M3 bolts.

# Gluing PV

Take endcaps and unions

# Final Recorder

Glue endcaps and unions together onto tube

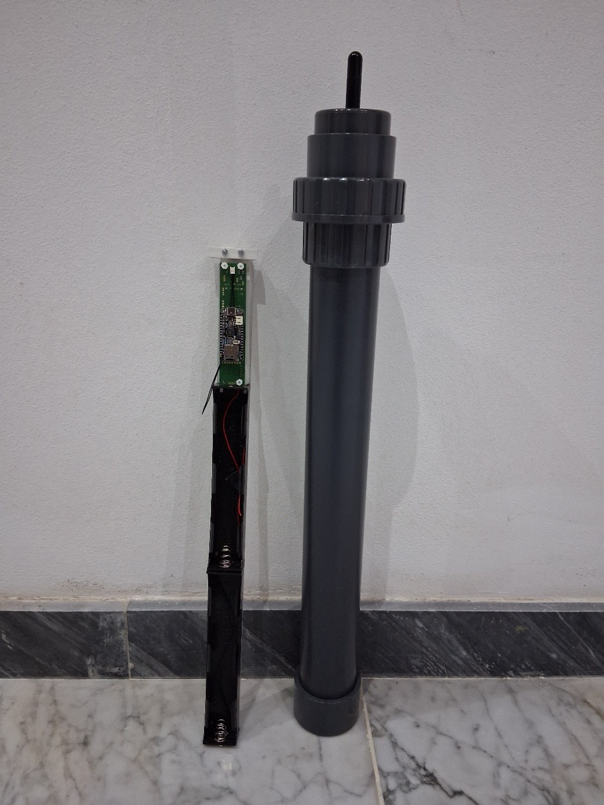
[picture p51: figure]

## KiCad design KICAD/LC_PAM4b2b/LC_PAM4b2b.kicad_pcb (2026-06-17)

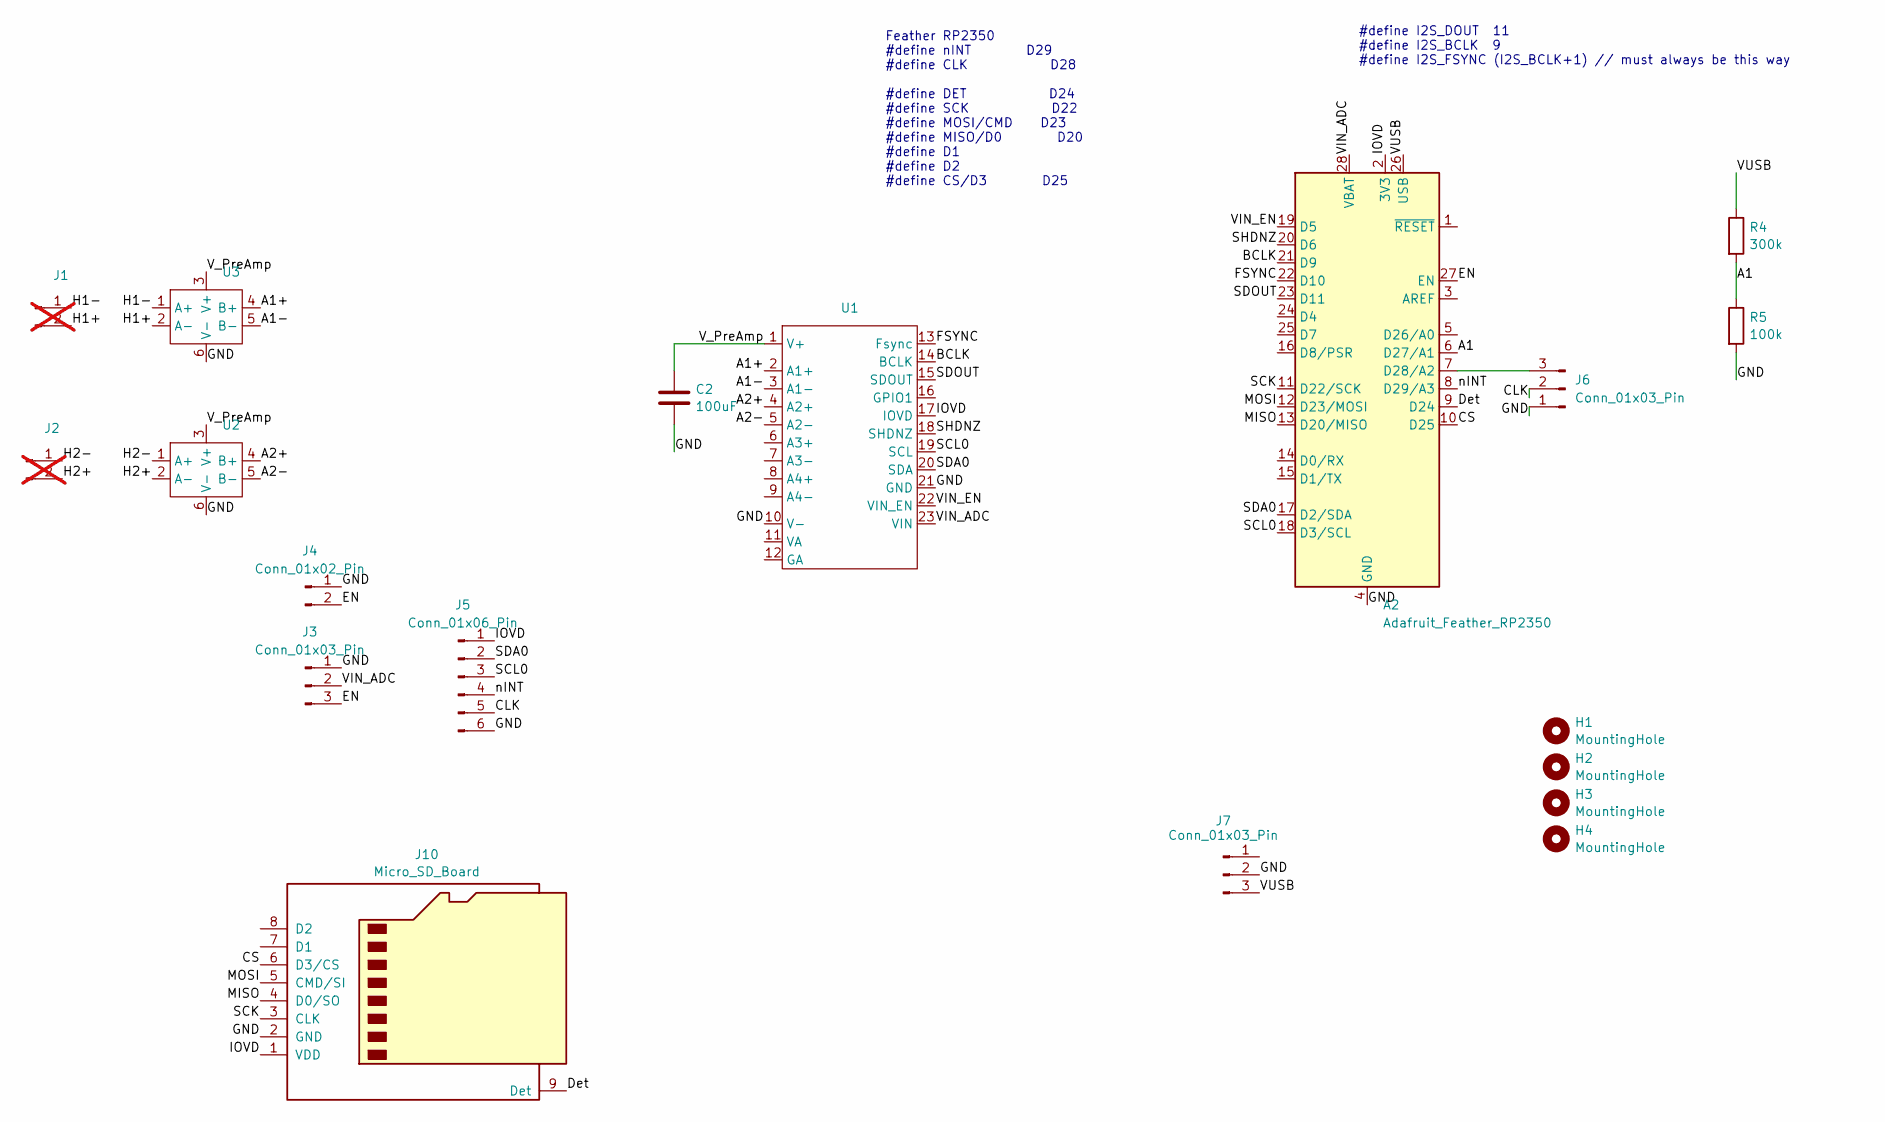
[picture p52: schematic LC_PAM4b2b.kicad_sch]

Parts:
A2: Adafruit_Feather_RP2350; Adafruit_Feather
C2: 100uF; CP_Radial_D4.0mm_P2.00mm
H1, H2, H3, H4: MountingHole; MountingHole_3.2mm_M3_DIN965
J1, J2: Conn_01x02_Male; Molex_PicoBlade_53048-0210_1x02_P1.25mm_Horizontal; not fitted
J3, J7: Conn_01x03_Pin; PinHeader_1x03_P2.54mm_Vertical
J4: Conn_01x02_Pin; PinHeader_1x02_P2.54mm_Vertical
J5: Conn_01x06_Pin; PinHeader_1x06_P2.54mm_Vertical
J6: Conn_01x03_Pin; PinHeader_1x03_P1.27mm_Vertical
J10: Micro_SD_Board; uSD
R4: 300k; R_Axial_DIN0204_L3.6mm_D1.6mm_P1.90mm_Vertical
R5: 100k; R_Axial_DIN0204_L3.6mm_D1.6mm_P1.90mm_Vertical
U1: ADC_V2
U2, U3: preAmp2

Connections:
/A1: A2.6 (D28/A1), R4.2, R5.1
/A1+: U1.2 (A1+), U3.4 (B+)
/A1-: U1.3 (A1-), U3.5 (B-)
/A2+: U1.4 (A2+), U2.4 (B+)
/A2-: U1.5 (A2-), U2.5 (B-)
/BCLK: A2.21 (D9), U1.14 (BCLK)
/CLK: J5.5, J6.2
/CS: A2.10 (D24), J10.6 (D3/CS)
/Det: A2.9 (D25), J10.9 (Det)
/EN: A2.27 (EN), J3.3, J4.2
/FSYNC: A2.22 (D10), U1.13 (Fsync)
/GND: A2.4 (GND), C2.2, J3.1, J4.1, J5.6, J6.1, J7.2, J10.2 (GND), R5.2, U1.10 (V-), U1.21 (GND), U2.6 (V-), U3.6 (V-)
/H1+: J1.2, U3.2 (A-)
/H1-: J1.1, U3.1 (A+)
/H2+: J2.2, U2.2 (A-)
/H2-: J2.1, U2.1 (A+)
/IOVD: A2.2 (3V3), J5.1, J10.1 (VDD), U1.17 (IOVD)
/MISO: A2.13 (D20/MISO), J10.4 (D0/SO)
/MOSI: A2.12 (D23/MOSI), J10.5 (CMD/SI)
/SCK: A2.11 (D22/SCK), J10.3 (CLK)
/SCL0: A2.18 (D3/SCL), J5.3, U1.19 (SCL)
/SDA0: A2.17 (D2/SDA), J5.2, U1.20 (SDA)
/SDOUT: A2.23 (D11), U1.15 (SDOUT)
/SHDNZ: A2.20 (D6), U1.18 (SHDNZ)
/VIN_ADC: A2.28 (VBAT), J3.2, U1.23 (VIN)
/VIN_EN: A2.19 (D5), U1.22 (VIN_EN)
/VUSB: A2.26 (USB), J7.3, R4.1
/V_PreAmp: C2.1, U1.1 (V+), U2.3 (V+), U3.3 (V+)
/nINT: A2.8 (D26/A3), J5.4
unnamed: A2.7 (D27/A2), J6.3

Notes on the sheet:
Feather RP2350 #define nINT D29 #define CLK D28 #define DET D24 #define SCK D22 #define MOSI/CMD D23 #define MISO/D0 D20 #define D1 #define D2 #define CS/D3 D25
#define I2S_DOUT 11 #define I2S_BCLK 9 #define I2S_FSYNC (I2S_BCLK+1) // must always be this way

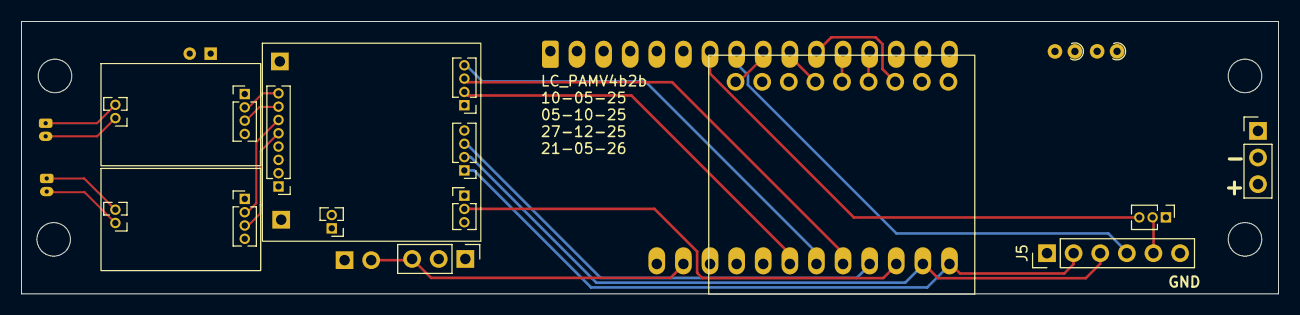
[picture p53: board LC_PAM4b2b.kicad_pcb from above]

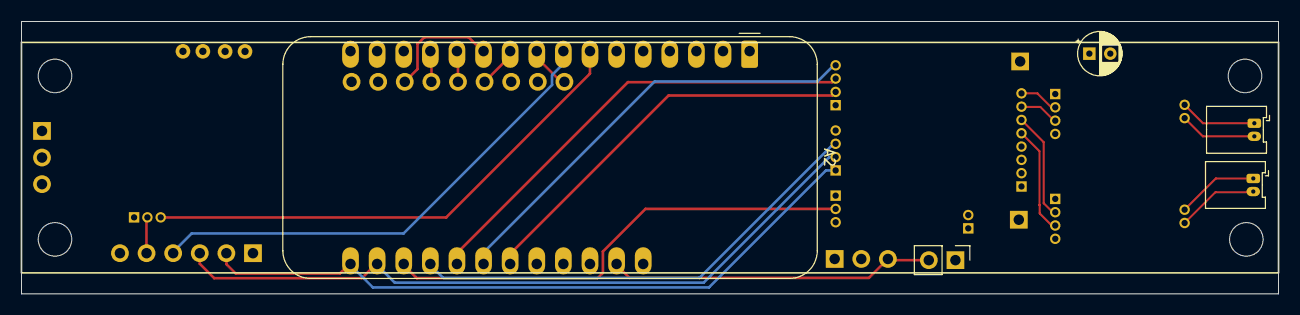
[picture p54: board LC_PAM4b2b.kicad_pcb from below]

Board: 4 copper layers, 120.0 x 26.0 mm, 19 parts (5 on the bottom side), 30 nets.

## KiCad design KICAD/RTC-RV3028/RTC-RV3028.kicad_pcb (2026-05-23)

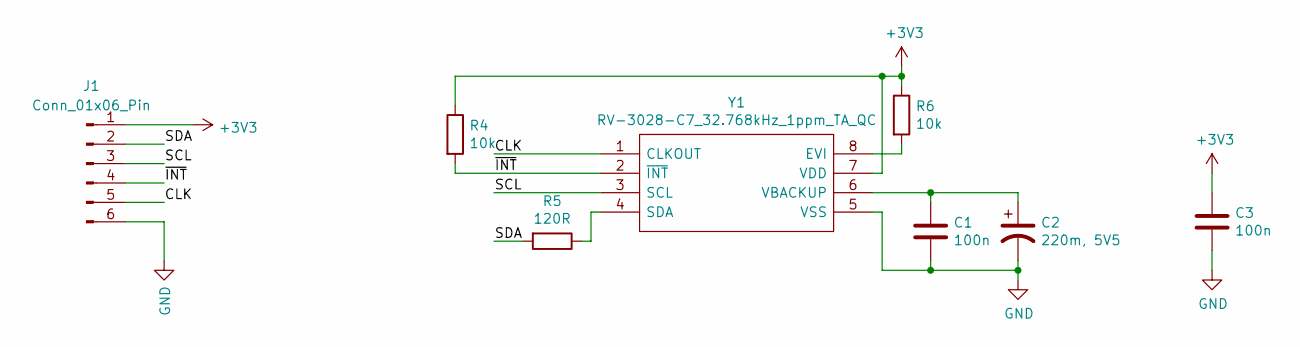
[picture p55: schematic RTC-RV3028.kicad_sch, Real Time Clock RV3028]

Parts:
C1, C3: 100n; C_0603_1608Metric
C2: 220m, 5V5; Kemet_FC_10.5X5.5
J1: Conn_01x06_Pin; PinHeader_1x06_P2.54mm_Vertical
R4, R6: 10k; R_0603_1608Metric
R5: 120R; C_0603_1608Metric
Y1: RV-3028-C7_32.768kHz_1ppm_TA_QC; MicroCrystal_RV3028C7; Mouser Part Number 428-203591-MG01

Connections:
+3V3: C3.1, J1.1, R4.1, R6.1, Y1.7 (VDD)
/CLK: J1.5, Y1.1 (CLKOUT)
/SCL: J1.3, Y1.3 (SCL)
/SDA: J1.2, R5.2
/~INT: J1.4, R4.2, Y1.2 (~INT)
GND: C1.2, C2.2, C3.2, J1.6, Y1.5 (VSS)
unnamed: R6.2, Y1.8 (EVI)
unnamed: R5.1, Y1.4 (SDA)
unnamed: C1.1, C2.1, Y1.6 (VBACKUP)

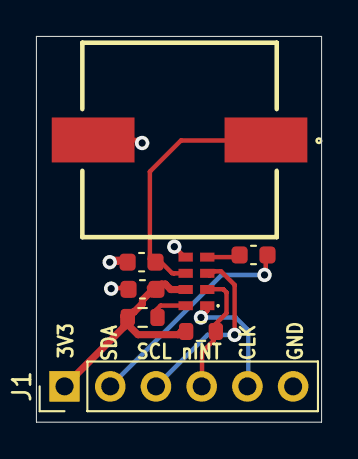
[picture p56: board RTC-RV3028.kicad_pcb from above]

Board: 2 copper layers, 15.8 x 21.4 mm, 8 parts (0 on the bottom side), 9 nets.

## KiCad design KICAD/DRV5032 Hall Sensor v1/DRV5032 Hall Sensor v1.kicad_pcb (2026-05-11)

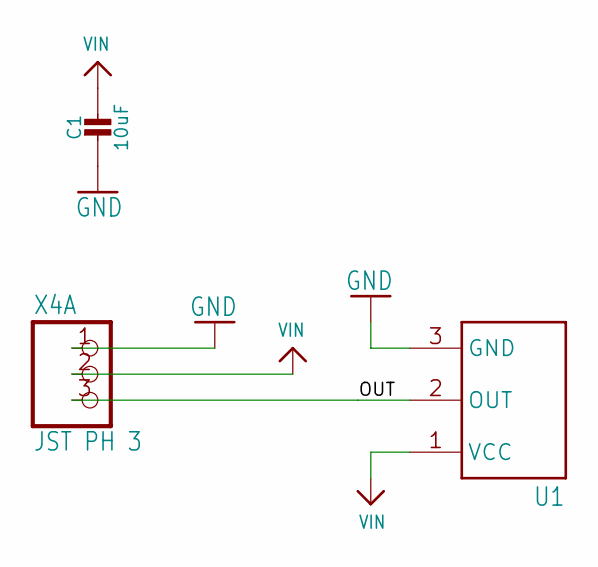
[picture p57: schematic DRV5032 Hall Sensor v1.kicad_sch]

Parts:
C1: 10uF; 0805-NO
U1: DRV5055A1QDBZT; SOT95P237X112-3N
X4: JST PH 3; JSTPH3

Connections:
GND: C1.2, U1.3 (GND), X4.1
OUT: U1.2 (OUT), X4.3
VIN: C1.1, U1.1 (VCC), X4.2

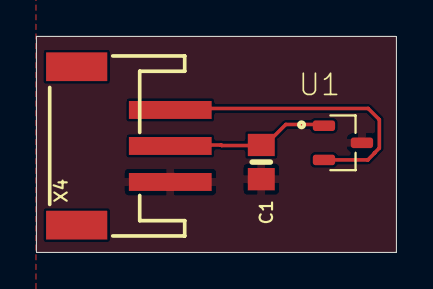
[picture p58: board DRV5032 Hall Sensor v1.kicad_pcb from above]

Board: 2 copper layers, 20.0 x 12.0 mm, 3 parts (0 on the bottom side), 3 nets.

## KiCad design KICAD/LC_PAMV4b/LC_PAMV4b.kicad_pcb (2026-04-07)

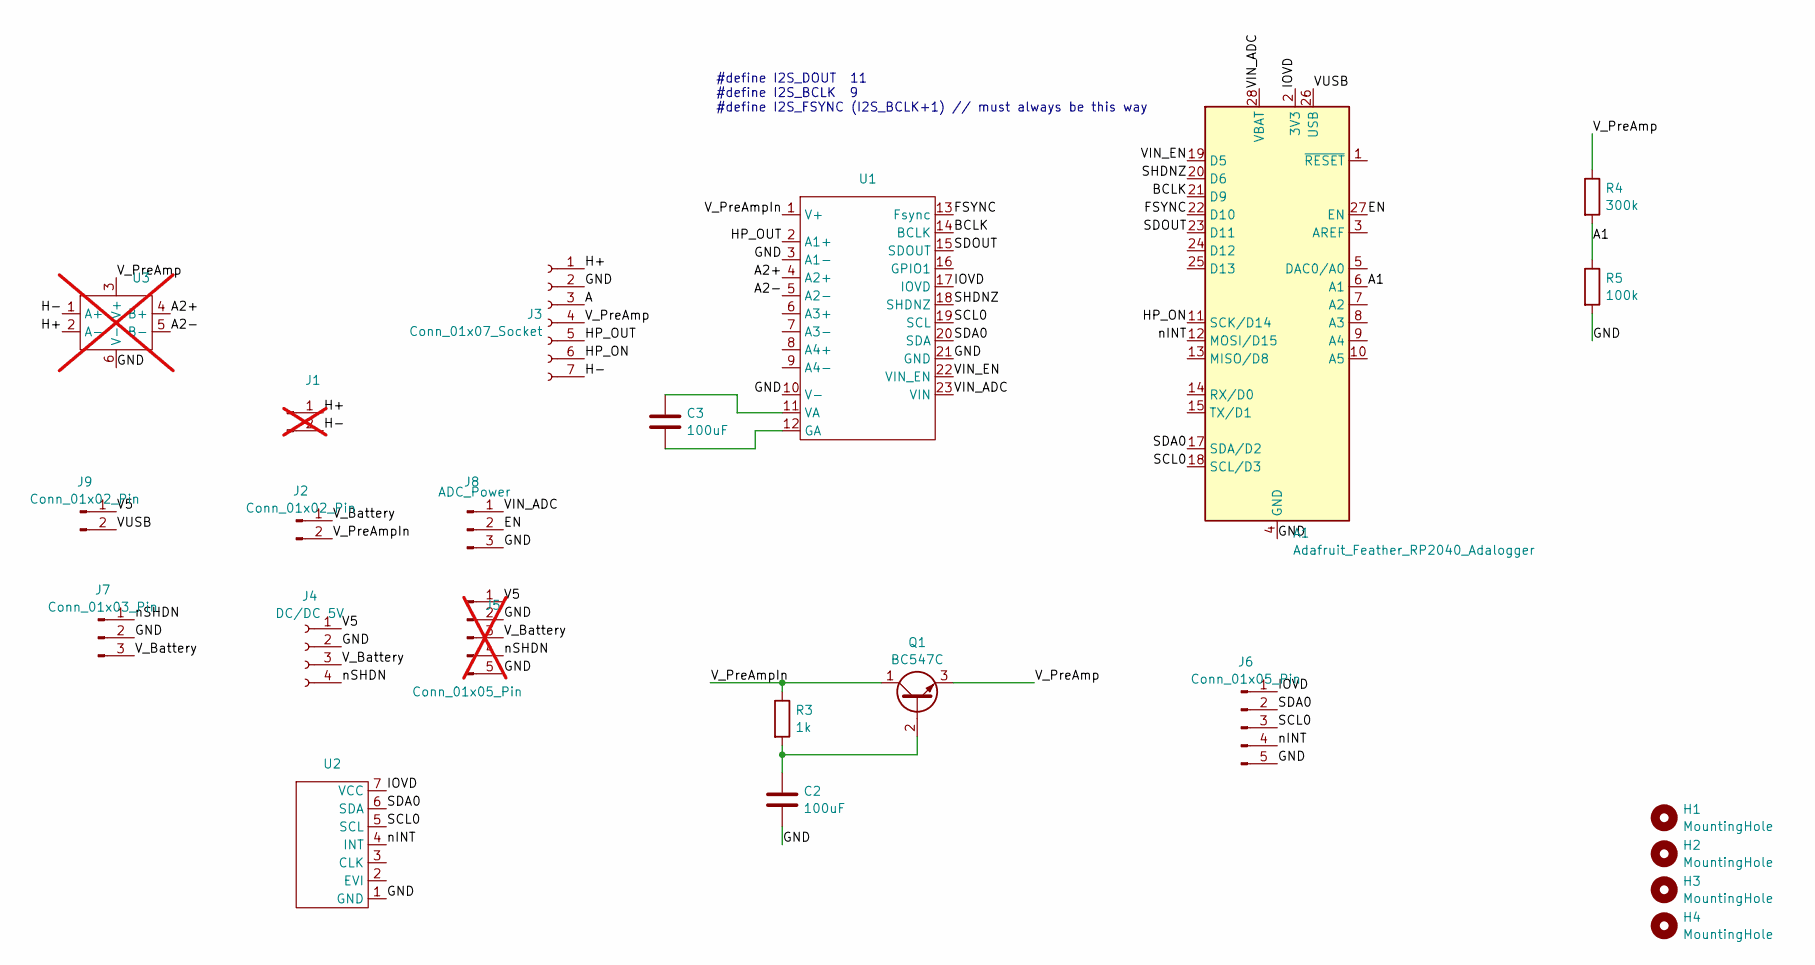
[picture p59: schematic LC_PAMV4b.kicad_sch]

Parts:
A1: Adafruit_Feather_RP2040_Adalogger; Adafruit_Feather_WithMountingHoles
C2, C3: 100uF; CP_Radial_D4.0mm_P2.00mm
H1, H2, H3, H4: MountingHole; MountingHole_3.2mm_M3_DIN965
J1: Conn_01x02_Male; Molex_PicoBlade_53048-0210_1x02_P1.25mm_Horizontal; not fitted
J2, J9: Conn_01x02_Pin; PinHeader_1x02_P2.00mm_Vertical
J3: Conn_01x07_Socket; HPAB
J4: DC/DC 5V; PinHeader_1x04_P2.54mm_Vertical
J5: Conn_01x05_Pin; PinHeader_1x05_P2.54mm_Vertical; not fitted
J6: Conn_01x05_Pin; PinHeader_1x05_P2.54mm_Vertical
J7: Conn_01x03_Pin; PinHeader_1x03_P2.54mm_Vertical
J8: ADC_Power; PinHeader_1x03_P2.54mm_Vertical
Q1: BC547C; TO-92_Inline
R3: 1k; R_Axial_DIN0204_L3.6mm_D1.6mm_P1.90mm_Vertical
R4: 300k; R_Axial_DIN0204_L3.6mm_D1.6mm_P1.90mm_Vertical
R5: 100k; R_Axial_DIN0204_L3.6mm_D1.6mm_P1.90mm_Vertical
U1: ADC_V2
U2: rtc2
U3: preAmp2; not fitted

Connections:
/A: J3.3
/A1: A1.6 (A1), R4.2, R5.1
/A2+: U1.4 (A2+), U3.4 (B+)
/A2-: U1.5 (A2-), U3.5 (B-)
/BCLK: A1.21 (D9), U1.14 (BCLK)
/EN: A1.27 (EN), J8.2
/FSYNC: A1.22 (D10), U1.13 (Fsync)
/GND: A1.4 (GND), A1.16 (GND), C2.2, J3.2, J4.2, J5.2, J5.5, J6.5, J7.2, J8.3, R5.2, U1.3 (A1-), U1.10 (V-), U1.21 (GND), U2.1 (GND), U3.6 (V-)
/H+: J1.1, J3.1, U3.2 (A-)
/H-: J1.2, J3.7, U3.1 (A+)
/HP_ON: A1.11 (SCK/D14), J3.6
/HP_OUT: J3.5, U1.2 (A1+)
/IOVD: A1.2 (3V3), J6.1, U1.17 (IOVD), U2.7 (VCC)
/SCL0: A1.18 (SCL/D3), J6.3, U1.19 (SCL), U2.5 (SCL)
/SDA0: A1.17 (SDA/D2), J6.2, U1.20 (SDA), U2.6 (SDA)
/SDOUT: A1.23 (D11), U1.15 (SDOUT)
/SHDNZ: A1.20 (D6), U1.18 (SHDNZ)
/V5: J4.1, J5.1, J9.1
/VIN_ADC: A1.28 (VBAT), J8.1, U1.23 (VIN)
/VIN_EN: A1.19 (D5), U1.22 (VIN_EN)
/VUSB: A1.26 (USB), J9.2
/V_Battery: J2.1, J4.3, J5.3, J7.3
/V_PreAmp: J3.4, Q1.3 (E), R4.1, U3.3 (V+)
/V_PreAmpIn: J2.2, Q1.1 (C), R3.1, U1.1 (V+)
/nINT: A1.12 (MOSI/D15), J6.4, U2.4 (INT)
/nSHDN: J4.4, J5.4, J7.1
unnamed: C2.1, Q1.2 (B), R3.2
unnamed: C3.2, U1.12 (GA)
unnamed: C3.1, U1.11 (VA)

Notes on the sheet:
#define I2S_DOUT 11 #define I2S_BCLK 9 #define I2S_FSYNC (I2S_BCLK+1) // must always be this way

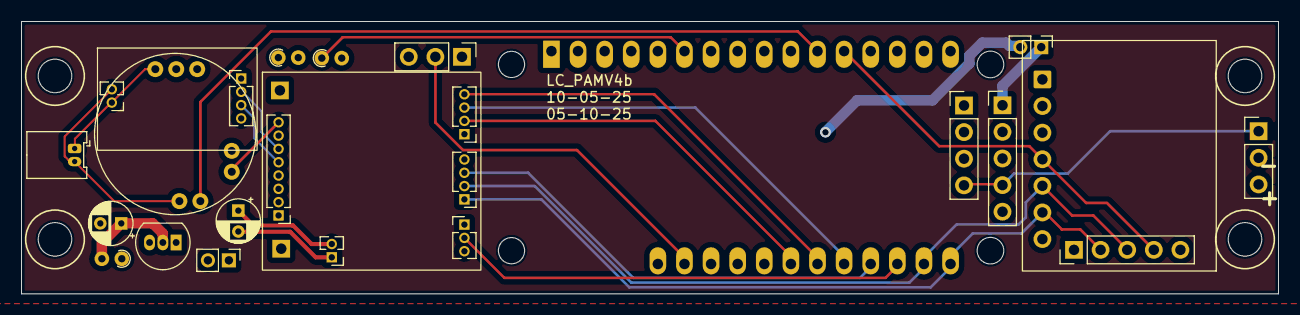
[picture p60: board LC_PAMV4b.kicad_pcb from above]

Board: 4 copper layers, 120.0 x 26.0 mm, 24 parts (1 on the bottom side), 28 nets.

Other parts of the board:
J10: rtc; rtc2

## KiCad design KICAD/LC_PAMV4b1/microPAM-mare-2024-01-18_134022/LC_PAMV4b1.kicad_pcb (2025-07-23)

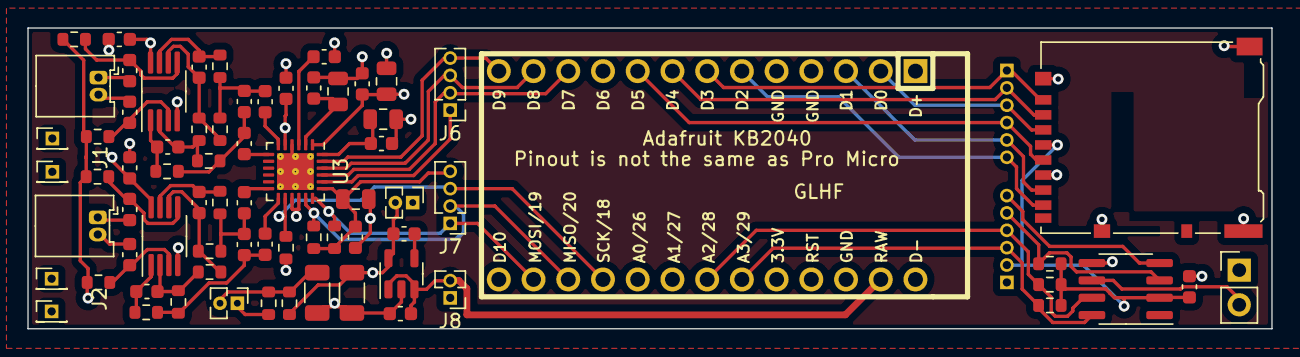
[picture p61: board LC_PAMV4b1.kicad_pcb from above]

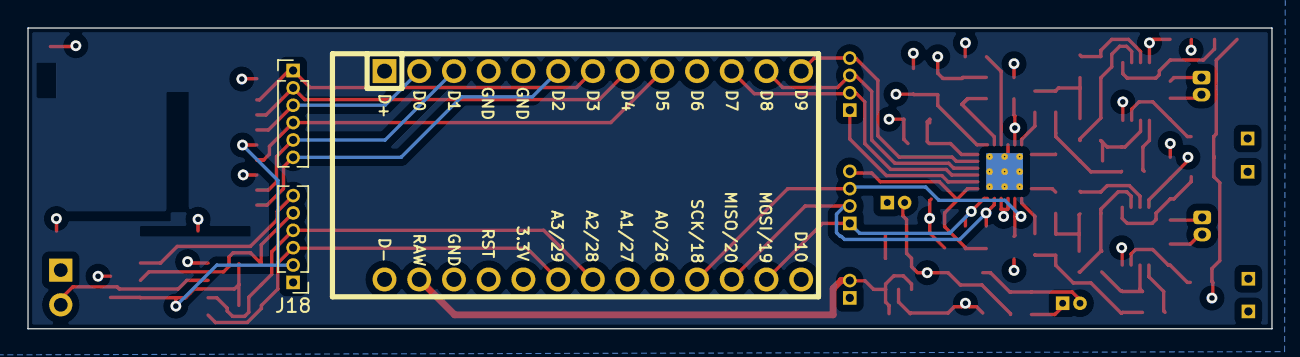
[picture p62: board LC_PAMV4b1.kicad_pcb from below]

Board: 4 copper layers, 91.0 x 22.0 mm, 74 parts (2 on the bottom side), 52 nets.

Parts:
C1, C2, C7, C8, C11, C12, C18, C19, C24, C28: 1u; C_0603_1608Metric
C3, C4, C9, C10: 15p; C_0603_1608Metric
C5, C6, C15, C16, C20, C23, C27, C29, C101: 0.1u; C_0603_1608Metric
C13, C14, C30: 10u; C_0805_2012Metric
C17, C22: 2700p; C_0603_1608Metric
C21: 1u; C_0805_2012Metric
C25, C26: 47u; C_1206_3216Metric
J1, J2: Conn_01x02_Male; Molex_PicoBlade_53048-0210_1x02_P1.25mm_Horizontal
J3, J4, J5, J11: Conn_01x01_Pin; PinHeader_1x01_P1.27mm_Vertical
J6, J7: Conn_01x04; PinHeader_1x04_P1.27mm_Vertical
J8: Conn_01x02; PinHeader_1x02_P1.27mm_Vertical
J9, J10: Conn_01x02_Pin; PinHeader_1x02_P1.27mm_Vertical
J14, J18: Conn_01x06_Pin; PinHeader_1x06_P1.27mm_Vertical
J15: Conn_01x02_Pin; PinHeader_1x02_P2.54mm_Vertical
J16: Micro_SD_Card_Det_Hirose_DM3AT; microSD_HC_Hirose_DM3AT-SF-PEJM5
R1, R7, R8, R14, R16: 10k; R_0603_1608Metric
R2, R3, R9, R10: 2M; R_0603_1608Metric
R4, R11: 1k; R_0603_1608Metric
R5, R6, R12, R13: 49R; R_0603_1608Metric
R15, R18, R101, R102, R103: 4.7k; R_0603_1608Metric
R17, R19: 100k; R_0603_1608Metric
U1, U2: AD8656; MSOP-8_3x3mm_P0.65mm
U3: TLV320ADC6140; QFN-24-1EP_4x4mm_P0.5mm_EP2.7x2.7mm_ThermalVias
U4: MIC5219-3.3YM5; SOT-23-5
U51: kb2040
U102: DS3232M; SOIC-8_3.9x4.9mm_P1.27mm

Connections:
/AVDD: C5.1, C6.1, C20.1, C21.1, C23.2, C25.1, J9.2, R17.1, U1.8 (V+), U2.8 (V+), U3.1 (AVDD), U4.5 (OUT)
/BCLK: J6.3, U3.22 (BCLK), U51.12 (D8)
/CMD: J14.3, J16.3 (CMD), U51.2 (D0)
/DAT0: J14.5, J16.7 (DAT0), U51.3 (D1)
/DAT1: J14.6, J16.8 (DAT1), U51.6 (D2)
/DAT2: J14.1, J16.1 (DAT2), U51.7 (D3)
/DAT3: J14.2, J16.2 (DAT3/CD), U51.8 (D4)
/DIn: J6.2, U3.21 (SDOUT), U51.11 (D7)
/FSYNC: J6.4, U3.23 (FSYNC), U51.13 (D9)
/GPIO1: J6.1, U3.20 (GPIO1)
/MicBias: C11.1, J3.1, J4.1, U3.5 (MICBIAS)
/SCK: J14.4, J16.5 (CLK), U51.9 (D5)
/SCL1: J7.2, R15.2, U3.17 (SCL_MOSI), U51.24 (MISO/20)
/SDA1: J7.1, R18.2, U3.18 (SDA_SSZ), U51.25 (MOSI/19)
/SHDNZ: J7.3, R16.2, U3.14 (SHDNZ), U51.23 (SCK/18)
/VCOM: C26.1, J10.2, R2.2, R3.1, R9.2, R10.1, R17.2, R19.1
/VIN: C27.2, J8.2, U4.1 (IN), U4.3 (EN), U51.15 (RAW)
/nRST: J18.6, U102.4 (~RST)
GND: C5.2, C6.2, C11.2, C12.2, C13.2, C14.2, C15.2, C16.2, C20.2, C21.2, C25.2, C26.2, C27.1, C29.2, C30.2, C101.2, J5.1, J8.1, J9.1, J10.1, J11.1, J15.1, J16.6 (VSS), J16.11 (SHIELD), J18.1, R16.1, R19.2, U1.4 (V-), U2.4 (V-), U3.4 (AVSS), U3.15 (ADDR1_MISO), U3.16 (ADDR0_SCLK), U3.25 (PAD), U4.2 (GND), U51.4 (GND), U51.5 (GND), U51.16 (GND), U102.5 (GND)
IOVD: C29.1, C30.1, C101.1, J7.4, J16.4 (VDD), J18.2, R15.1, R18.1, R101.1, R102.1, R103.1, U3.19 (IOVD), U51.18 (3.3v), U102.2 (VCC)
unnamed: C3.2, R5.2, U1.1
unnamed: C4.1, R6.2, U1.7
unnamed: C9.2, R12.2, U2.1
unnamed: C10.1, R13.2, U2.7
unnamed: C17.1, C19.2, R1.1, R5.1
unnamed: C17.2, C18.2, R6.1, R7.1
unnamed: C22.1, C28.2, R8.1, R12.1
unnamed: C22.2, C24.2, R13.1, R14.1
unnamed: C2.2, J1.1
unnamed: C1.2, J1.2
unnamed: C8.2, J2.1
unnamed: C7.2, J2.2
unnamed: C1.1, R2.1, U1.3 (+)
unnamed: C3.1, R1.2, R4.1, U1.2 (-)
unnamed: C2.1, R3.2, U1.5 (+)
unnamed: C4.2, R4.2, R7.2, U1.6 (-)
unnamed: C7.1, R9.1, U2.3 (+)
unnamed: C9.1, R8.2, R11.1, U2.2 (-)
unnamed: C8.1, R10.2, U2.5 (+)
unnamed: C10.2, R11.2, R14.2, U2.6 (-)
unnamed: C13.1, C16.1, U3.2 (AREG)
unnamed: C14.1, C15.1, U3.24 (DREG)
unnamed: C19.1, U3.7 (IN1M_GPO1)
unnamed: C18.1, U3.6 (IN1P_GPI1)
unnamed: C28.1, U3.13 (IN4M_GPO4)
unnamed: C24.1, U3.12 (IN4P_GPI4)
unnamed: C12.1, U3.3 (VREF)
unnamed: C23.1, U4.4 (BP)
SCL0: J18.3, R101.2, U51.19 (A3/29), U102.8 (SCL)
SDA0: J18.4, R102.2, U51.20 (A2/28), U102.7 (SDA)
VBAT: J15.2, U102.6 (VBAT)
nINT: J18.5, R103.2, U102.3 (~INT/SQW)

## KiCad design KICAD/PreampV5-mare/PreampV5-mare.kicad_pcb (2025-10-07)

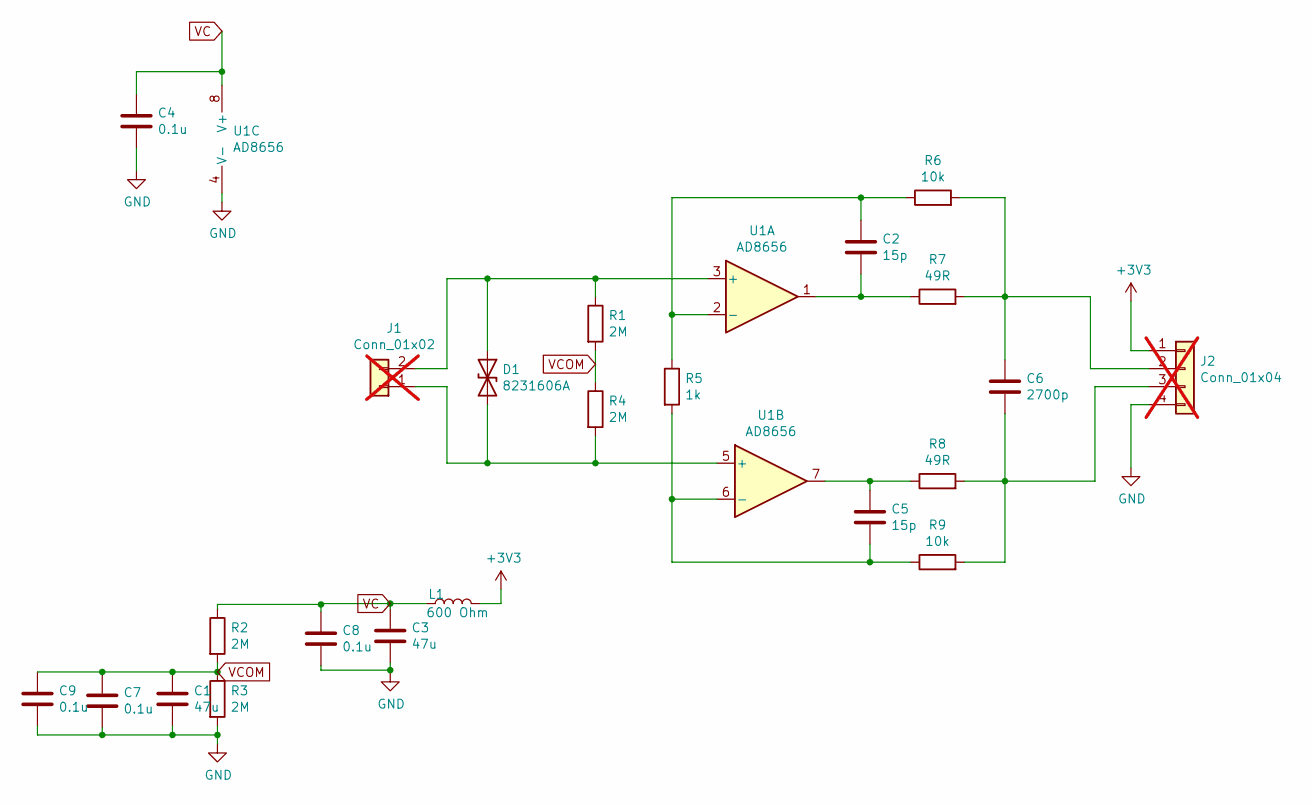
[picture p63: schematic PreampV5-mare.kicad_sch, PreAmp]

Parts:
C1, C3: 47u; C_0805_2012Metric
C2, C5: 15p; C_0402_1005Metric
C4, C7, C8, C9: 0.1u; C_0402_1005Metric
C6: 2700p; C_0402_1005Metric
D1: 8231606A; D_0603_1608Metric
J1: Conn_01x02; PinHeader_1x02_P1.27mm_Vertical; not fitted
J2: Conn_01x04; PinHeader_1x04_P1.27mm_Vertical; not fitted
L1: 600 Ohm; L_0603_1608Metric
R1, R2, R3, R4: 2M; R_0402_1005Metric
R5: 1k; R_0402_1005Metric
R6, R9: 10k; R_0402_1005Metric
R7, R8: 49R; R_0402_1005Metric
U1: AD8656; MSOP-8_3x3mm_P0.65mm

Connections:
+3V3: J2.1, L1.2
GND: C1.2, C3.2, C4.2, C7.2, C8.2, C9.2, J2.4, R3.2, U1.4 (V-)
unnamed: C2.2, R7.1, U1.1
unnamed: C5.1, R8.1, U1.7
unnamed: D1.1 (A1), J1.2, R1.1, U1.3 (+)
unnamed: D1.2 (A2), J1.1, R4.2, U1.5 (+)
unnamed: C6.1, J2.2, R6.2, R7.2
unnamed: C6.2, J2.3, R8.2, R9.2
unnamed: C2.1, R5.1, R6.1, U1.2 (-)
unnamed: C5.2, R5.2, R9.1, U1.6 (-)
VC: C3.1, C4.1, C8.1, L1.1, R2.1, U1.8 (V+)
VCOM: C1.1, C7.1, C9.1, R1.2, R2.2, R3.1, R4.1


Board: 2 copper layers, 15.5 x 10.0 mm, 23 parts (0 on the bottom side), 12 nets.

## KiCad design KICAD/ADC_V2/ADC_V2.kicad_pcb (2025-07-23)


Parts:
C1, C25: 47u; CP_EIA-3216-12_Kemet-S
C2, C3, C4, C5, C6, C7, C11, C12, C18, C19: 1u; C_0603_1608Metric
C13, C14, C30: 10u; CP_EIA-2012-15_AVX-P
C15, C16, C20, C23, C27, C29: 0.1u; C_0603_1608Metric
C21: 1u; CP_EIA-2012-15_AVX-P
J1: Conn_01x08_Pin; PinHeader_1x08_P1.27mm_Vertical; not fitted
J2, J5: Conn_01x01_Pin; PinHeader_1x01_P2.54mm_Vertical; not fitted
J3: Conn_01x03; PinHeader_1x03_P1.27mm_Vertical; not fitted
J6, J7: Conn_01x04; PinHeader_1x04_P1.27mm_Vertical; not fitted
J9: Conn_01x02_Pin; PinHeader_1x02_P1.27mm_Vertical; not fitted
L1: BLM18HG601SN1D; L_0603_1608Metric
R15, R16, R18: 10k; R_0603_1608Metric
U3: TLV320ADC6140; QFN-24-1EP_4x4mm_P0.5mm_EP2.7x2.7mm_ThermalVias
U4: MIC5219-3.3YM5; SOT-23-5

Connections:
/AVDD: C20.1, C21.1, C25.1, J9.2, U3.1 (AVDD), U4.5 (OUT)
/BCLK: J6.3, U3.22 (BCLK)
/FSYNC: J6.4, U3.23 (FSYNC)
/GPIO1: J6.1, U3.20 (GPIO1)
/IOVD: C29.1, C30.1, J7.4, R15.1, R18.1, U3.19 (IOVD)
/MicBias: C11.1, J2.1, U3.5 (MICBIAS)
/SCL: J7.2, R15.2, U3.17 (SCL_MOSI)
/SDA: J7.1, R18.2, U3.18 (SDA_SSZ)
/SDOUT: J6.2, U3.21 (SDOUT)
/SHDNZ: J7.3, R16.2, U3.14 (SHDNZ)
/VIN: C1.1, C27.2, L1.1, U4.1 (IN)
/VIN_EN: J3.2, U4.3 (EN)
GND: C1.2, C11.2, C12.2, C13.2, C14.2, C15.2, C16.2, C20.2, C21.2, C23.1, C25.2, C27.1, C29.2, C30.2, J3.1, J5.1, J9.1, R16.1, U3.4 (AVSS), U3.15 (ADDR1_MISO), U3.16 (ADDR0_SCLK), U3.25 (PAD), U4.2 (GND)
unnamed: C7.2, J1.1
unnamed: C6.2, J1.2
unnamed: C5.2, J1.3
unnamed: C4.2, J1.4
unnamed: C3.2, J1.5
unnamed: C2.2, J1.6
unnamed: C19.2, J1.7
unnamed: C18.2, J1.8
unnamed: J3.3, L1.2
unnamed: C13.1, C16.1, U3.2 (AREG)
unnamed: C14.1, C15.1, U3.24 (DREG)
unnamed: C19.1, U3.7 (IN1M_GPO1)
unnamed: C18.1, U3.6 (IN1P_GPI1)
unnamed: C3.1, U3.9 (IN2M_GPO2)
unnamed: C2.1, U3.8 (IN2P_GPI2)
unnamed: C5.1, U3.11 (IN3M_GPO3)
unnamed: C4.1, U3.10 (IN3P_GPI3)
unnamed: C7.1, U3.13 (IN4M_GPO4)
unnamed: C6.1, U3.12 (IN4P_GPI4)
unnamed: C12.1, U3.3 (VREF)
unnamed: C23.2, U4.4 (BP)

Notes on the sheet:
https://www.allaboutcircuits.com/technical-articles/clean-power-for-every-ic-part-1-understanding-bypass-capacitors/



Board: 4 copper layers, 21.0 x 19.0 mm, 35 parts (7 on the bottom side), 34 nets.

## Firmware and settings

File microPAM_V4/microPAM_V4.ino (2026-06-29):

/* microPAM 
 * Copyright (c) 2026, Walter Zimmer
 *
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
 * THE SOFTWARE IS PROVIDED "AS IS", WITHOUT WARRANTY OF ANY KIND, EXPRESS OR
 * IMPLIED, INCLUDING BUT NOT LIMITED TO THE WARRANTIES OF MERCHANTABILITY,
 * FITNESS FOR A PARTICULAR PURPOSE AND NONINFRINGEMENT. IN NO EVENT SHALL THE
 * AUTHORS OR COPYRIGHT HOLDERS BE LIABLE FOR ANY CLAIM, DAMAGES OR OTHER
 * LIABILITY, WHETHER IN AN ACTION OF CONTRACT, TORT OR OTHERWISE, ARISING FROM,
 * OUT OF OR IN CONNECTION WITH THE SOFTWARE OR THE USE OR OTHER DEALINGS IN
 * THE SOFTWARE.
 */
//
#include <Arduino.h>

#include "src/global.h"
#if MCU==T_4_1
  #include "src/Teensy.h"
#else
  #include "src/rp2x.h"
#endif

#include "src/adc.h"
#include "src/rtc.h"
#include "src/process.h"
#include "src/classifier.h"
#include "src/menu.h"
#include "src/filing.h"
#include "src/utils.h"
/********************************* basics *******************************************************/
//  enum status_t  {DO_START, CLOSED, RECORDING, MUST_STOP, JUST_STOPPED, STOPPED, MUST_HIBERNATE};
char status_text[7][16]=
  {"DO_START\0", "CLOSED\0", "RECORDING\0", "MUST_STOP\0", "JUST_STOPPED\0", "STOPPED\0", "MUST_HIBERNATE\0"};

status_t status=STOPPED;

volatile uint32_t fsamp=FSAMP;

#if MCU == T_4_1
  void acqSetup(void)
  { if(fsamp>FSAMP) fsamp=FSAMP; 
    dsp_init();
    acqInit(fsamp);
    acqStart();
  }
#else
  void core1_main(void) 
  { if(fsamp>FSAMP) fsamp=FSAMP; 
    acqInit(fsamp);
    acqStart();
    while (true) {asm("wfi");}
  }

  void acqSetup(void)
  { // Launch core 1
    multicore_launch_core1(core1_main);
  }
#endif
/********************************* main *********************************************************/
void setup() {
  // put your setup code here, to run once:
  //set_MCU_clock(CLK_MULT);

  while(millis()<5000) if(Serial) break;
  if(Serial)
  { Serial.println("\n*** micoPAM ***");
    Serial.print("millis: "); Serial.println(millis());
  }

  printCrashReport();
  //
  getUID();
  Serial.print("uid ");Serial.println(uid_strng);

  systemInit();

  rtc_setup();
  //
  have_disk=SD_init();
  Serial.print("have disk: "); Serial.println(have_disk);
  configShow();

  queue.reset();
  process_init();
  //
  acqSetup();

  status=STOPPED;
  status=CLOSED;
}

//extern float D[];
volatile uint32_t loop_count=0;
volatile uint32_t loop1_count=0;
volatile uint32_t loop1_timer=0;

void printMonitor(const char *type, uint32_t cnt, uint32_t *loop_count, uint32_t * buffer)
{ if(!Serial) return;
//            Serial.printf("1- %d %d %3d %3d %4d us %.3f ms (%4.1f%%) ",cnt++, acq_count, fsamp*NCHAN_I2S/NBUF_I2S, acq_missed, 
//                    process_max_us, (1000.0f*NBUF_I2S)/(fsamp*NCHAN_I2S),process_max_us/(10000.0f*acq_count));
//            Serial.printf("%2d: ",loop1_count);
  Serial.print(type); Serial.print(cnt); 
  Serial.print(" "); Serial.print(acq_count);
  Serial.print(" "); Serial.print( (fsamp*NCHAN_I2S)/NBUF_I2S);
  Serial.print(" "); Serial.print(acq_missed);
  Serial.print(" "); Serial.print((1000.0f*NBUF_I2S)/(fsamp*NCHAN_I2S));
  Serial.print(" "); Serial.print(process_max_us);
  #if MCU==T_4_1
  Serial.print(" "); Serial.print(dsp_isr_max_us);
  Serial.print(" "); Serial.print(classifier_exec_us);
  #endif
  acq_count=0;
  acq_missed=0;
  process_max_us=0;
  #if MCU==T_4_1
  dsp_isr_max_us=0;
  #endif
  Serial.print(" "); Serial.print(*loop_count);
  *loop_count=0;
  #if MCU==T_4_1
  Serial.print(" "); printFloat(Imax,3);
  Imax=0.0f;
  #endif
  Serial.print(": ");
  for(int ii=0;ii<4;ii++)  { Serial.print(" "); printHex32(buffer[ii],0);}
  #if (MCU==T_4_1) && (PROC_MODE==4)
    Serial.print(" mu:");
    for(int ii=0;ii<VAE_LAT_TOTAL;ii++) { Serial.print(" "); Serial.print(vae_mu[ii],4); }
    Serial.print(" sig:"); Serial.print(vae_mu_signal_count);
    if(vae_mu_signal_count > 0)
    { Serial.print(" mu_sig:");
      for(int ii=0;ii<VAE_LAT_TOTAL;ii++) { Serial.print(" "); Serial.print(vae_mu_signal[ii]/vae_mu_signal_count,4); }
      for(int ii=0;ii<VAE_LAT_TOTAL;ii++) vae_mu_signal[ii]=0.0f;
      vae_mu_signal_count=0;
    }
  #else
    for(int ii=4;ii<10;ii++) { Serial.print(" "); printHex32(buffer[ii],1);}
  #endif
  Serial.println();
}

void loop() {
  // put your main code here, to run repeatedly:
  static uint32_t cnt;

  status = menu(status);
  if(status==DO_START)
  { //Serial.print("status: ");Serial.println(status_text[old_status]);
    adc_init();
    status=CLOSED;
  }
  if(status==JUST_STOPPED)
  { adc_exit();
    status=STOPPED;
  }
  if(status==MUST_HIBERNATE)
  { // 

  }

  if(queue.available()>0)
  {
    if(have_disk)
    { // 
      if(status != STOPPED) // have disk and started acquisition
      { status =logger(status);
        //
        #if MONITOR==1 // to monitor during writing
          { loop1_count++;
            //
            static uint32_t to=0;
            if(millis()>to+1000)
            { to=millis();
              for(int ii=0; ii<10;ii++) logBuffer[ii]=diskBuffer[ii];
              printMonitor("1 - ", cnt++, (uint32_t *)&loop1_count, logBuffer);
            }
          }
        #endif
      }
      else // have disk but stopped
      {
        queue.pull(diskBuffer);
      }
    } 
    else  // have no disk
    {
      queue.pull(diskBuffer);

      if(status < MUST_STOP) // started acquisition but no disk
      {
        loop_count++;
        static uint32_t to=0;
        if(millis()>to+1000)
        { to=millis();
          for(int ii=0; ii<10;ii++) logBuffer[ii]=diskBuffer[ii];
          printMonitor("0 - ", cnt++, (uint32_t *) &loop_count, logBuffer);
        }
      }
      // simulate stopping process (in case there is no disk)
      if(status==MUST_STOP) {status=JUST_STOPPED; Serial.println("\njust stopped");}
    }
  }
  // testimg hibernate
  #if 0
    if(millis()>30000)
    { uint32_t tt=rtc_get();
      hibernate_until((tt/60+1)*60);
    }
  #endif
  asm("wfi");
}

/*
Some performance numbers

rp2040: single preamp 1B34342E
rp2350: no preamps    D6919ED7
T4.1:   dual preamps  E51382FB

# default speed
single channel  96 kHz rp2040 (200 MHz)    60.3mA @ 5.1V
dual channel    96 kHz rp2350 (150 MHz)    34.3mA @ 5.1V 
dual channel   384 kHz rp2350 (150 MHz)    42.3mA @ 5.1V
dual channel    96 kHz T4.1   (600 Mhz)   104.6mA @ 5.1V
dual channel   384 kHz T4.1   (600 Mhz)   114.7mA @ 5.1V

# same speed
single channel  96 kHz rp2040 (150 MHz)    54.9mA @ 5.1V  h: 1.4mA @ 5.11V  p: 825 uS (7.8%) 2nd:  827 uS (7.8%)
dual channel    96 kHz rp2350 (150 MHz)    34.3mA @ 5.1V  h: 3.6mA @ 5.11V  p: 712 uS (6.7%) 2nd: ~890 uS (8.4%)
dual channel    96 kHz T4.1   (150 Mhz)    76.5mA @ 5.1V  h: 0.5mA @ 5.11V  p: 298 uS (2.8%) n/a

#cpu 150 MHz (384/192 kHz)
mcu     acq   disk nb      mA      proc(us)
rp2040  192   12    e    71.5 ( 840; 15.8%)
rp2350  755   36    a    76.5 ( 780; 29.1%)
T4.1    755   51    e   134.5 ( 369; 11.7%)

150 MHz (192 kHz)
rp2040  192   12    e    71.5 ( 840; 15.8%) 
rp2350  378   18    a    57.3 ( 782; 14.7%) 
T4.1    382   26    e   128.0 ( 305;  6.8%) 

T4_1
 4chan 192 kHz 600MHz
  388 acq/s
 no procesing 
  343 us  (6.2%)  175mA
 4 spectra 50% overlap
  600 us  (12.2%) 179mA

comment previous % may be wrong estimates
-------------------------------------------------------------------
TD-1.61
32-06-26 15:00 4-chan 192 kHz
RP2350(150 MHz)  755 750 743 us 1.333 ms (56.1%) 36  (no dsp_apply)
T4.1(600 MHz)    376 375 131 us 2.667 ms ( 4.9%) 27  (no dsp_apply)
T4.1(600 MHz)    380 375 565 us 2.667 ms (21.5%) 32  (with dsp_apply)
*/

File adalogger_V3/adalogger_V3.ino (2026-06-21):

/* microPAM 
 * Copyright (c) 2023/2024/2025/2026, Walter Zimmer
 *
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
 * THE SOFTWARE IS PROVIDED "AS IS", WITHOUT WARRANTY OF ANY KIND, EXPRESS OR
 * IMPLIED, INCLUDING BUT NOT LIMITED TO THE WARRANTIES OF MERCHANTABILITY,
 * FITNESS FOR A PARTICULAR PURPOSE AND NONINFRINGEMENT. IN NO EVENT SHALL THE
 * AUTHORS OR COPYRIGHT HOLDERS BE LIABLE FOR ANY CLAIM, DAMAGES OR OTHER
 * LIABILITY, WHETHER IN AN ACTION OF CONTRACT, TORT OR OTHERWISE, ARISING FROM,
 * OUT OF OR IN CONNECTION WITH THE SOFTWARE OR THE USE OR OTHER DEALINGS IN
 * THE SOFTWARE.
 */
#include <stdio.h>
#include <string.h>
#include "pins_arduino.h"

#include "src/global.h"
#include "src/rp2040.h"
#include "src/mRTC.h"
#include "src/Menu.h"
#include "src/Filing.h"
#include "src/Adc.h"
#include "src/Queue.h"

#include "Wire.h"
#include "src/I2C.h"

//-----------------------------------
// implementation
//-----------------------------------

status_t status=STOPPED;
uint32_t loop_count=0;
uint32_t data_count=0;

uint16_t have_disk=0;
uint16_t setup_ready=0;
uint16_t setup1_ready=0;
char status_text[6][16]={"DO_START\0", "CLOSED\0", "RECORDING\0", "MUST_STOP\0", "JUST_STOPPED\0", "STOPPED\0"};

// some testing modes
#define TEST_HIBERNATE 0
#define TEST_I2C 1
#define TEST_RTC 0
#define TEST_XRTC 0

void setup() {
  // put your setup code here, to run once:
  // reduce MCU clock
  set_sys_clock_khz(CLK_MULT*12000, true);

  #if TEST_HIBERNATE==1 // test hibernates
  { 

    while(!Serial);
    pinMode(LED_BUILTIN,OUTPUT);
    digitalWrite(LED_BUILTIN, HIGH);
    i2s_setup();
    dma_setup();
    uint32_t xrtc=rtc_setup();
    datetime_t tm;
    uint32_t tt;
    while(1)
    {
      for(int ii=0;ii<10;ii++)
      { Serial.println(ii);
        delay(1000);
      }
      XRTCgetDatetime(&tm);
      tt= date2time(&tm, 2000);
      Serial.println(tt);

      digitalWrite(LED_BUILTIN, LOW);
      tt= (tt/60 +1)*60;
      Serial.println(tt);
      hibernate_until(tt); // wakes up to to the last full minute less than tt
    }
  }
  #endif

  #if TEST_I2C==1
  // test i2c connections
    {
      while(!Serial);
      #define ADC_EN      5
      #define ADC_SHDNZ   6

      if(1)
      { Serial.println("Power on ADC");
        pinMode(ADC_EN,OUTPUT);
        acqPower(HIGH);
        pinMode(ADC_SHDNZ,OUTPUT);
        adcReset();
        delay(100);
        adcStart();
      }

      Serial.println("wire");
      test_wire(&Wire);
      Serial.println("wire1");
      test_wire(&Wire1);
      neo_pixel_show(0, 0, 10);
      while(1);
    }  
  #endif

  neo_pixel_init();
  neo_pixel_show(10, 0, 0);

  // check if not XRTC wake-up
  pinMode(XRTC_INT_PIN,INPUT_PULLUP);
  if(!digitalRead(XRTC_INT_PIN))  
  { status=DO_START;
  }
  else
  { while(millis()<(WAIT*1000)) if(Serial) break;
    Serial.print(millis());
  }
  if(Serial) Serial.println("\n***********\nAdalogger\n***********\n");
  neo_pixel_show(10, 10, 0);

  if (1)
  for(int p=0;p<PINS_COUNT;p++) // disable GIPOs (to save power,hopefully)
  { if(p==PIN_NEOPIXEL) continue; // neopixel
    if(p==XRTC_INT_PIN) continue;
    #if MCU==RP_2350
      if(p==RP2350_PSRAM_CS) continue; // psram
    #endif
    pinMode(p, INPUT); 
    gpio_set_input_enabled(p, false); 
  }
  
  // set mcu rtc
  // put it to some time so it is running
  // it will be synchronized to external rtc later
  if(1)
  { const datetime_t setTime = { 2026, 1, 1, 4, 0, 0, 0 };
    rtc_init();
    rtc_set_datetime( &setTime); 
    Serial.print("rtc running "); Serial.println(rtc_running());
    //
    datetime_t t;
    rtcGetDatetime(&t);
    printDatetime("rtc",&t);
  }

  #if test_RTC==1  // check time stamp
    // activate for testing rtc
    while(1)
    { // for testing
      delay(1000);
      datetime_t t;
      rtcGetDatetime(&t);
      printDatetime("rtc",&t);
    }
  #endif

  // set-up external rtc
  int xrtc=0;
  xrtc=rtc_setup();
  Serial.print("xrtc "); Serial.println(xrtc);

  #if TEST_XRTC==1 // check times
    // sync is done in mRTC.cxx
    if(xrtc)
    {
      datetime_t t;
      XRTCgetDatetime(&t);  
      rtcSetDatetime(&t);  
      Serial.println("Corrected time is");
      printDatetime("rtc",&t);
    }
  #endif

  have_disk=SD_init();
  Serial.print("have disk: "); Serial.println(have_disk);

  Serial.println("\nConfiguration Parameters");
  configShow();

  Serial.print("Start Time: ");Serial.println(startTime);
  datetime_t tm;
  decodeTimestamp(&tm,startTime);
  uint32_t to=0;
  to=date2time(&tm,2000);
  uint32_t tt = rtc_get();
  Serial.println(tt);
  Serial.println(to);
  if((tt<to) & (to<tt+365*24*3600))
  {
    neo_pixel_show(0, 0, 0);
    hibernate_until(to);
  }

  //if(have_disk) status=DO_START;
  if(!have_disk)  neo_pixel_show(0, 0, 10); 
  else 
  {
    neo_pixel_show(0, 0, 0);
    status=DO_START;
  }

  #if MC==0
    // have single core; start acquisition here
    i2s_setup();
    dma_setup();
  #else
    // have dual core; release and wait for setup of second core 
    setup_ready=1;
    while(!setup1_ready) delay(10);
  #endif
  //

  if(!Serial)
  { //usb_stop(); // may be useful to cut power consumption further but hinders development
  }
  Serial.print("status: ");Serial.println(status_text[status]);
}

extern uint32_t diskBuffer[];
void loop() {
  // put your main code here, to run repeatedly:
  //
  // management
  //status_t old_status=status;
  status = menu(status);
  if(status==DO_START)
  { //Serial.print("status: ");Serial.println(status_text[old_status]);
    adc_init();
    status=CLOSED;
    neo_pixel_show(0, 0, 0);
  }
  if(status==JUST_STOPPED)
  { adc_exit();
    status=STOPPED;
    neo_pixel_show(0, 10, 0);
  }
  if(status==MUST_HIBERNATE)
  { // 

  }
  //
  // filing
  int ndc=getQueueCount();
  if(ndc>0)
  { if(have_disk)
    { // write data to disk to clean up
      if(status != STOPPED)
      { 
        status=logger(status);
        data_count++;
      }
      else
      {
        pullQueue(diskBuffer);
      }
    }
    else
    { // write some data every second to screen
      pullQueue(diskBuffer);

      if(status < MUST_STOP)
      { 
        static uint32_t t0=0;
        if(millis()>t0+1000)
        { t0=millis();
          Serial.print(acq_count); Serial.print(" ");Serial.print(missed_acq); Serial.print(" "); acq_count=0; missed_acq=0;
          Serial.print(ndc); Serial.print(": ");
          for(int ii=0;ii<8;ii++) Serial.printf("%08x ",diskBuffer[ii]); Serial.println();
        }
      }
      // simulate stopping process
      if(status==MUST_STOP) {status=JUST_STOPPED; Serial.println("\njust stopped");}
    }
  }
  //
  loop_count++;
  asm("wfi");
}

#if MC==1
  void setup1(void)
  { while(!setup_ready) delay(100);
    Serial.println("setup1");
    i2s_setup();
    dma_setup();
    setup1_ready=1;
  }

  void loop1(void)
  {
    asm("wfi");
  }
#endif

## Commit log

2024-07-26 initial upload
    [ADC_V2.kicad_pcb, ADC_V2.kicad_sch, LC_PAM.kicad_pcb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]
2024-08-02 adapted adc to 2ß24 hw
2024-08-04 changed reference day
    [LC_PAM.kicad_pcb]
2024-08-19 update baseboard
    [LC_PAM.kicad_pcb, LC_PAM.kicad_sch]
2024-09-19 added pream-FET
    [PreampFET-mare.kicad_pcb, PreampFET-mare.kicad_sch]
2024-09-27 updated for fet-preamp
    [LC_PAM.kicad_pcb, LC_PAM.kicad_sch, PreampFET-mare.kicad_pcb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]
2025-02-07 added LC_PAM_sp.step
    [LC-mare.FCStd, LC_PAM.kicad_pcb, LC_PAM_sp.step]
2025-08-08 added adalogger_v2
    [config.txt]
2025-11-21 Nov update
    [LC_PAMV4b.kicad_pcb, LC_PAMV4b.kicad_sch, LC_PAMV4c.kicad_pcb]
2025-12-30 corrected insertChunk
2026-01-10 Removed development files
    [ADC.kicad_sch, ADC_LC.kicad_pcb, ADC_LC.kicad_sch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]
2026-01-10 removed LC_ADC
    [LC_ADC.kicad_pcb, LC_ADC.kicad_sch, microPAM_V4.kicad_sch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]
2026-02-09 Update Assembly
2026-05-09 switch between rp2040 and rp2350
2026-05-10 corrected wav file queueing
    [microPAM.py]
2026-05-11 add hall sensor
    [DRV5032 Hall Sensor v1.kicad_pcb, DRV5032 Hall Sensor v1.kicad_sch]
2026-05-17 created RTC-RV3028
    [RTC-RV3028.kicad_pcb, RTC-RV3028.kicad_sch]
2026-05-19 Add LC_PAM4b2b
    [LC_PAM4b2b.kicad_pcb, LC_PAM4b2b.kicad_sch, microPAM_V4.kicad_sch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]
2026-05-23 corrected hibernate
    [LC_PAM4b2b.kicad_pcb, LC_PAM4b2b.kicad_sch, RTC-RV3028.kicad_pcb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]
2026-05-24 wav file meta data corrected
    [microPAM.py]
2026-05-26 corrected meta information processing
    [microPAM.py]
2026-06-01 KICAD new components
2026-06-17 drill file
    [LC_PAM4b2b.kicad_pcb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]
2026-06-23 replaced Serial-printf bysequences of Serial.print
    [global.h, microPAM_V4.ino]
2026-06-23 rewrote print(,HEX)
2026-06-23 use logBuffer for printout
2026-06-25 Add detection, build automation, and cross-platform fixes
    - Threshold detector: exponential-averaging background (Dmean) and peak
    (Dpeak) with configurable DETECT_ALPHA / DETECT_THR in global.h
    - Memory/safety fixes: sscanf width limits, off-by-one in menu, volatile
    busy flag for multicore safety, insertChunk overflow fence
    - RP2040/RP2350: fixed missing Dmean/Dsnr/Dpeak definitions, stale extern,
    preprocessor guard; added systemInit() with neo_pixel_init on RP targets
    - Build automation: build.ps1 (all three targets), flash_teensy/rp2040/rp2350.ps1
    - CLAUDE.md: project documentation for targets, compile commands, architecture
    - .gitignore: exclude build/ and .build/ output directories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
    [global.h, microPAM_V4.ino]
2026-06-27 version 4.2.0: add compressed spectrum mode, async DSP dispatch, synthetic test signal
    - New PROC_MODE numbering: 2=spectrum (.spc), 3=intensity (.int), 4=intensity+VAE (.vae)
    - Async DSP via IRQ_QTIMER3: process() snapshots buffer and returns immediately
    - spectrum_power(): per-bin FFT magnitude, scale2=(1<<(31-SHIFT))
    - Separate scale3=(1<<(32-SHIFT)) for intensity output (modes 3/4)
    - USE_SYNTH_SIGNAL: synthetic chirp injection via synth_chirp_generate() in utils.cxx
    - process_init() resets synth state and fills EXTMEM synth_signal[] at startup
    - PGAIN removed from scale computation; PGAIN set to 0
    [global.h, microPAM_V4.ino]
2026-06-27 compiled rp-boards
2026-06-28 version 4.3.0: PROC_MODE 4 result vector, data browser, Python tools consolidation
    Firmware:
    - PROC_MODE 4: new result vector (magic, millis, signal_flag, detection_excess,
    vae_detect[4], vae_mu[16], optional I[3x512]) written by classifier ISR
    - push_pair() queue method: atomic header+I matrix push into same disk block
    - classifier_isr: per-VAE background EMA, detection score, signal-frame I snapshot
    - printMonitor: guard dsp_isr_max_us, classifier_exec_us, Imax in #if MCU==T_4_1
    (fixes RP2040/RP2350 build failure)
    Python:
    - micropam_reader.py: consolidated (decompress.py inlined, removed as separate file)
    - micropam_browser.py: new file browser + data viewer (modes 0-4, matplotlib)
    -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
    [global.h, microPAM_V4.ino, micropam_browser.py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]
2026-06-29 add vae_model_analysis.py; update all docs with VAE persistence and analysis tool
    - Python/vae_model_analysis.py: new script; reads VAE_backup snapshots, produces 5-page PDF report
    - Docs/vae_edge_computing.md/pdf: fix backup path (/VAE_backup/); add Section 9 (post-processing analysis)
    - Docs/micropam_python_tools.md/pdf: add vae_model_analysis tool entry and full dedicated section
    - Readme.md: add VAE model/backup rows to classifier table; add simulator.py and vae_model_analysis.py to source file table; add vae_model_analysis subsection under Python tools
    - build: update all three target binaries
    [vae_model_analysis.py]
2026-11-05 upload KICAD mods
2026-11-05 more KICAD mods
2026-11-12 microPAM_V3 3.5.13: package of commit e5a5046 with documents/
    Adds documents/lcmare_cal.pdf (calibration workflow for LC-Mare) and
    documents/characterization_1B843C2E.pdf (endurance, gain, input noise and
    self-noise of one recorder); README.txt describes both.
